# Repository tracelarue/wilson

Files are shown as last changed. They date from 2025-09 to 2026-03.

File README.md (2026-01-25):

# Wilson 🤖
A robot for autonomous beverage retrieval, powered by Gemini

Updated (9/30/25)

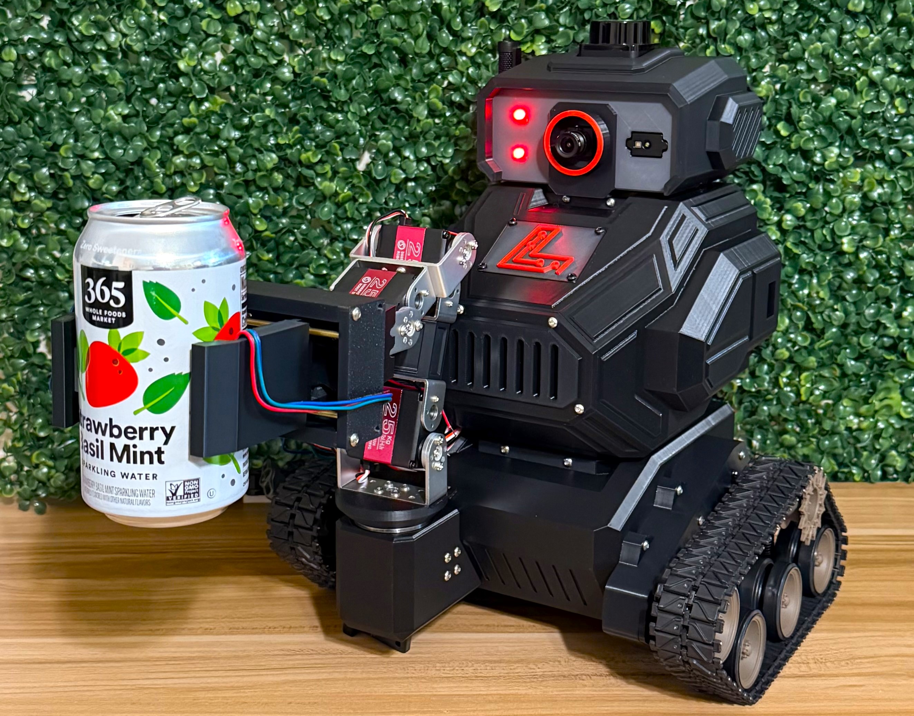
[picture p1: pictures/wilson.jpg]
Wilson Robot


## About Wilson

Wilson is an autonomous robot featuring a differential drive base and a 4-DOF manipulator arm, designed to be your personal beverage assistant! With Google's Gemini Live API, Wilson can conversationally interact with users and execute tasks based on natural language requests. His main directive? **Getting you a drink from the mini fridge!** *(in development)*

### Why I Built Wilson

I wanted to create a robot that could bridge the gap between advanced AI capabilities and real-world physical interaction. The goal was to build something impressive technically, build a robust set of robotics skills, and impress any guest who comes to my house - starting with the simple (but apparently not so simple), satisfying task of fetching drinks on command.

### How Wilson Works

Wilson operates on **ROS2 Humble** and combines a wide range of hardware and sensors:

**🧠 AI & Interaction:**
- Google Gemini Live API for natural conversation and task understanding
- Real-time audio/visual processing for environmental awareness
- Tool execution based on conversational commands

**🔧 Hardware:**
- **Computing**: Raspberry Pi 5 (8GB) as the main brain
- **Control**: 2 Arduino Nanos for drive and arm control
- **Sensors**: 
  - LD-19 LiDAR for navigation and mapping
  - AruCam ToF camera for depth perception  
  - USB camera for visual recognition
  - Microphone for listening to the user
  - Novel soft 3D force sensor in the gripper (developed by Dr. Jonathan Miller, et al. at the University of Kansas)
- **Motors**:
  - 2, GA37-520 DC motors with integrated encoders
  - 5, 20 kg digital servos
- **Power**:
  - 3S, 5200 mAh LiPo battery
- **Other**:
  - USB Speaker for responding to the user

## 🦾🔨 Design & Manufacturing

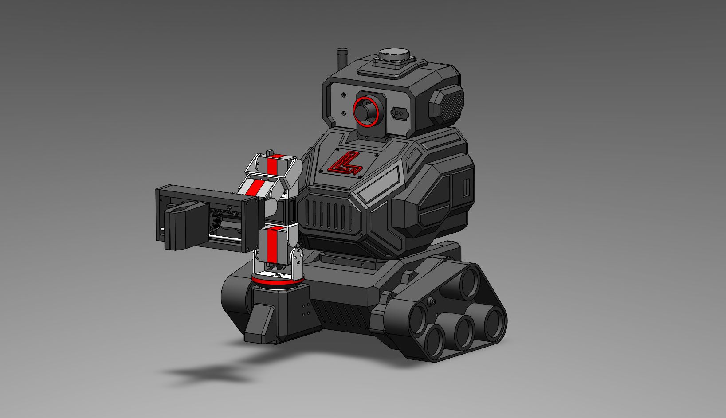
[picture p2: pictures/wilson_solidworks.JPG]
SolidWorks CAD Design

*SolidWorks CAD Design - The original 3D model*

I designed every component of Wilson (except the tracks/wheels) in SolidWorks and 3D printed the entire chassis and manipulator at home.

Wilson was designed with modularity and servicability in mind. The head, body, base, and track mounts are all seperate components to allow for easier fixes and design changes down the road. 

All of Wilson's electronic components are mounted internally on a modular rail system. This allows for easy removal of components for fixing or upgrading.

## Simulation & Testing 👨‍💻
Wilson's simulation leverages both **Gazebo** and **RViz** for an accelerated robotics development workflow:

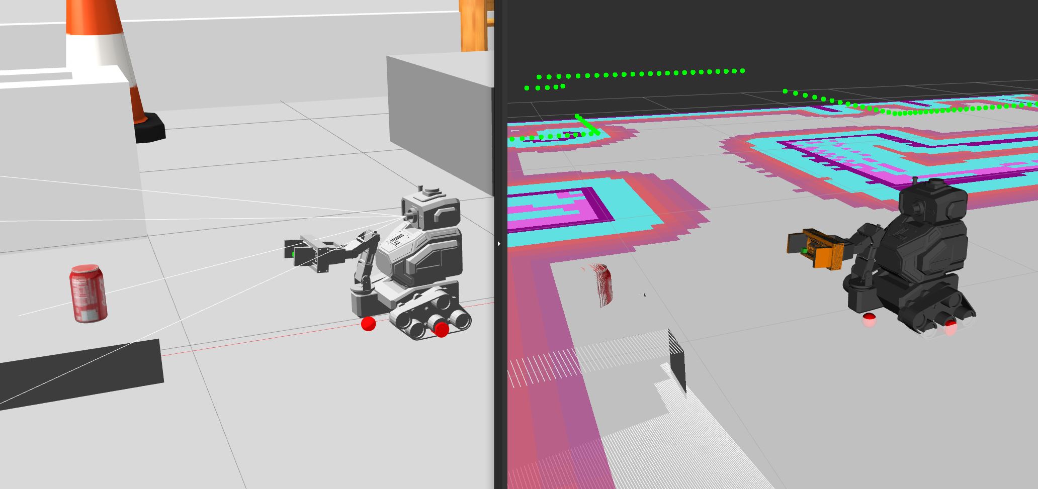
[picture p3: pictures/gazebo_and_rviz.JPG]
Gazebo wimulation with Rviz live data visualization


### Gazebo Simulation

Gazebo provides a realistic 3D environment where Wilson's physical model, sensors, and actuators are simulated. You can simulate Wilson navigating, manipulating objects, and interacting with its environment just like in the real world. The simulation includes:

- Physics-based movement and collisions
- Sensor emulation (LiDAR, cameras, force sensors)
- Interactive objects (Coke can)

### RViz Visualization

RViz is used for visualizing sensor data, robot state, and planning. In Wilson's simulation, RViz displays:

- The robot model
- Real-time LiDAR scans, depth camera point clouds, and images from a simulated camera
- Navigation maps and planned paths
- Manipulator arm trajectories
- AI-generated position markers for detected objects

You can use RViz panels to send navigation goals, control the arm, and monitor AI perception outputs. This combination of Gazebo and RViz enables rapid testing and debugging of Wilson's autonomous and conversational capabilities before deploying to hardware.

#### Navigation Demo
In this video, Wilson is asked to go to the living room. For the purpose of this demo, I have enabled text input and output, but when Wilson is aroudn the house, you would speak this command to him and he would respond accordingly.
AI controlled navigation demo

## Contact

Please feel free to submit issues or ideas for further improvement! 

Maintained by Trace LaRue:
traceglarue@gmail.com

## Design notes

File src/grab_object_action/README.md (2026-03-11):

# Grab Object Action Server

A ROS2 action server for grabbing drinks using MoveIt Task Constructor.

## Overview

This package provides an action server that accepts grab requests with drink coordinates in the `depth_camera_link_optical` frame and executes a grab sequence using MoveIt Task Constructor.

## Action Interface

### Action Name
`grab_object`

### Goal Message
```
float64 targetx                          # X-coordinate of drink (in depth_camera_link_optical frame)
float64 targety                          # Y-coordinate of drink (in depth_camera_link_optical frame)
float64 targetz                          # Z-coordinate of drink (in depth_camera_link_optical frame)
```

**Notes:**
- All coordinates are in the `depth_camera_link_optical` frame
- Drink dimensions are hardcoded (height: 0.122m, radius: 0.033m for standard can size)

### Feedback Message
```
string current_stage                     # Current execution stage
float32 progress_percentage              # Progress (0-100%)
```

### Result Message
```
bool success                             # Whether the grab succeeded
string message                           # Status/error message
geometry_msgs/Pose final_drink_pose      # Final drink pose in world frame
```

## Building

```bash
cd ~/wilson
colcon build --packages-select grab_object_action
source install/setup.bash
```

## Usage

### Launch the Action Server

```bash
ros2 launch grab_object_action grab_object_server.launch.py
```

### Send a Goal via Command Line

```bash
# Basic example - grab objectat x=0, y=0.1, z=0.65 in depth_camera_link_optical frame
ros2 action send_goal /grab_object grab_object_action/action/GrabObject "{
  targetx: 0.0,
  targety: 0.06,
  targetz: 0.375
}" --feedback
```

### Send a Goal from Python

```python
import rclpy
from rclpy.action import ActionClient
from rclpy.node import Node
from grab_object_action.action import GrabObject
from geometry_msgs.msg import Point

class GrabObjectClient(Node):
    def __init__(self):
        super().__init__('grab_object_client')
        self._action_client = ActionClient(self, GrabObject, 'grab_object')

    def send_goal(self, x, y, z):
        goal_msg = GrabObject.Goal()
        goal_msg.targetx = x
        goal_msg.targety = y
        goal_msg.targetz = z

        self._action_client.wait_for_server()

        send_goal_future = self._action_client.send_goal_async(
            goal_msg,
            feedback_callback=self.feedback_callback
        )
        send_goal_future.add_done_callback(self.goal_response_callback)

    def goal_response_callback(self, future):
        goal_handle = future.result()
        if not goal_handle.accepted:
            self.get_logger().info('Goal rejected')
            return

        self.get_logger().info('Goal accepted')
        result_future = goal_handle.get_result_async()
        result_future.add_done_callback(self.result_callback)

    def feedback_callback(self, feedback_msg):
        feedback = feedback_msg.feedback
        self.get_logger().info(f'Stage: {feedback.current_stage}, Progress: {feedback.progress_percentage}%')

    def result_callback(self, future):
        result = future.result().result
        if result.success:
            self.get_logger().info(f'Success! {result.message}')
        else:
            self.get_logger().error(f'Failed: {result.message}')

def main(args=None):
    rclpy.init(args=args)
    client = GrabObjectClient()

    # Example: grab object at position relative to depth camera
    client.send_goal(x=0.45, y=-0.07, z=0.1, frame='depth_camera_link_optical')

    rclpy.spin(client)

if __name__ == '__main__':
    main()
```

## Features

- **Dynamic Frame Transformation**: Automatically transforms target coordinates from the specified frame to the world frame
- **Standard Drink Dimensions**: Uses hardcoded dimensions optimized for standard can size (height: 0.122m, radius: 0.033m)
- **Progress Feedback**: Provides real-time feedback on execution progress
- **Dynamic Approach Vector**: Computes approach direction based on robot base position
- **Full Grab Sequence**: Executes complete grab sequence including:
  - Open gripper
  - Move to pre-grasp position
  - Approach drink
  - Generate grasp pose
  - Close gripper
  - Attach drink
  - Lift drink
  - Return home

## Configuration

The action server uses the following MoveIt group names (defined in the source code):
- **arm_group**: `"arm"`
- **hand_group**: `"gripper"`
- **hand_frame**: `"end_effector_frame"`

To change these, modify the constants in [src/grab_object_action_server.cpp](src/grab_object_action_server.cpp:334-336).

## Troubleshooting

### Action server not available
Make sure the action server is running and MoveIt is properly configured:
```bash
ros2 action list
# Should show: /grab_object
```

### Transform errors
Ensure all required TF frames are being published:
```bash
ros2 run tf2_ros tf2_echo base_link depth_camera_link_optical
```

### Planning failures
Check that:
1. The target position is reachable
2. MoveIt is properly configured for your robot
3. Collision checking is not too restrictive

## Dependencies

- `rclcpp`
- `rclcpp_action`
- `moveit_task_constructor_core`
- `tf2_ros`
- `geometry_msgs`
- `shape_msgs`

## License

TODO: Add license information

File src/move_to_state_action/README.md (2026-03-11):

# move_to_state_action

ROS2 Humble action server for moving robot groups to named states using MoveIt. This package provides a simple, reusable interface for commanding the robot to move to predefined poses defined in the SRDF.

## Overview

The `move_to_state_action` package provides an action server that:
1. Accepts a named state as input (e.g., "ready", "zero", "open")
2. Automatically detects which MoveIt planning group the state belongs to
3. Plans and executes motion to reach the target state
4. Provides real-time feedback during planning and execution

**Key Feature**: Field names have **no underscores** (`statename` instead of `state_name`) for full compatibility with MCP (Model Context Protocol) servers.

## Features

- **Auto-Detection**: Automatically determines which group (arm/gripper) a state belongs to by querying the SRDF
- **Simple Interface**: Single string input - just provide the state name
- **MCP Compatible**: Field names without underscores work seamlessly with MCP servers
- **Safe Execution**: Uses MoveIt's collision checking and motion planning
- **Real-time Feedback**: Progress updates during planning and execution
- **Error Handling**: Graceful handling of invalid states, planning failures, and execution errors

## Prerequisites

### System Requirements
- ROS2 Humble
- MoveIt 2
- Robot with SRDF containing named group states

### Available States (Wilson Robot)

Based on [wilson.srdf](../wilson_moveit_config/config/wilson.srdf):

**Arm States:**
- `ready` - Default ready position
- `idle` - Idle/rest position
- `zero` - All joints at zero
- `ready_to_grab` - Pre-grasp position
- `ground_grab` - Low grabbing position
- `air_grab` - Mid-air grabbing position

**Gripper States:**
- `open` - Gripper fully open
- `close` - Gripper fully closed
- `can` - Gripper sized for a can

## Installation

1. Package is located in your ROS2 workspace:
   ```bash
   cd ~/wilson/src/move_to_state_action
   ```

2. Build the package:
   ```bash
   cd ~/wilson
   colcon build --packages-select move_to_state_action --symlink-install
   source install/setup.bash
   ```

## Usage

### Launch the Action Server

```bash
# Source your workspace
source ~/wilson/install/setup.bash

# Launch the action server
ros2 launch move_to_state_action move_to_state_server.launch.py

# For simulation (with sim time)
ros2 launch move_to_state_action move_to_state_server.launch.py use_sim_time:=true
```

### Send Action Goals

**Command Line:**
```bash
# Move arm to ready position
ros2 action send_goal /move_to_state move_to_state_action/action/MoveToState \
  "{statename: 'idle'}" --feedback

# Move arm to zero position
ros2 action send_goal /move_to_state move_to_state_action/action/MoveToState \
  "{statename: 'zero'}" --feedback

# Open gripper
ros2 action send_goal /move_to_state move_to_state_action/action/MoveToState \
  "{statename: 'open'}" --feedback

# Close gripper to can size
ros2 action send_goal /move_to_state move_to_state_action/action/MoveToState \
  "{statename: 'can'}" --feedback
```

**Python Client:**
```python
import rclpy
from rclpy.action import ActionClient
from rclpy.node import Node
from move_to_state_action.action import MoveToState

class MoveToStateClient(Node):
    def __init__(self):
        super().__init__('move_to_state_client')
        self._action_client = ActionClient(self, MoveToState, 'move_to_state')

    def send_goal(self, state_name):
        goal_msg = MoveToState.Goal()
        goal_msg.statename = state_name  # Note: no underscore (MCP compatible!)

        self._action_client.wait_for_server()
        self._send_goal_future = self._action_client.send_goal_async(
            goal_msg, feedback_callback=self.feedback_callback)
        self._send_goal_future.add_done_callback(self.goal_response_callback)

    def feedback_callback(self, feedback_msg):
        feedback = feedback_msg.feedback
        self.get_logger().info(
            f'{feedback.currentstatus} ({feedback.progresspercentage:.1f}%)')

    def goal_response_callback(self, future):
        goal_handle = future.result()
        if not goal_handle.accepted:
            self.get_logger().info('Goal rejected')
            return

        self.get_logger().info('Goal accepted')
        self._get_result_future = goal_handle.get_result_async()
        self._get_result_future.add_done_callback(self.get_result_callback)

    def get_result_callback(self, future):
        result = future.result().result
        if result.success:
            self.get_logger().info(f'Success! {result.message}')
        else:
            self.get_logger().error(f'Failed: {result.message}')

def main(args=None):
    rclpy.init(args=args)
    client = MoveToStateClient()
    client.send_goal('ready')
    rclpy.spin(client)
    rclpy.shutdown()

if __name__ == '__main__':
    main()
```

**C++ Client:**
```cpp
#include <rclcpp/rclcpp.hpp>
#include <rclcpp_action/rclcpp_action.hpp>
#include "move_to_state_action/action/move_to_state.hpp"

using MoveToState = move_to_state_action::action::MoveToState;
using GoalHandleMoveToState = rclcpp_action::ClientGoalHandle<MoveToState>;

class MoveToStateClient : public rclcpp::Node {
public:
    MoveToStateClient() : Node("move_to_state_client") {
        client_ = rclcpp_action::create_client<MoveToState>(this, "move_to_state");
    }

    void send_goal(const std::string& state_name) {
        if (!client_->wait_for_action_server(std::chrono::seconds(10))) {
            RCLCPP_ERROR(this->get_logger(), "Action server not available");
            return;
        }

        auto goal_msg = MoveToState::Goal();
        goal_msg.statename = state_name;  // Note: no underscore (MCP compatible!)

        auto send_goal_options = rclcpp_action::Client<MoveToState>::SendGoalOptions();
        send_goal_options.feedback_callback =
            [this](auto, const auto feedback) {
                RCLCPP_INFO(this->get_logger(), "%s (%.1f%%)",
                    feedback->currentstatus.c_str(),
                    feedback->progresspercentage);
            };

        client_->async_send_goal(goal_msg, send_goal_options);
    }

private:
    rclcpp_action::Client<MoveToState>::SharedPtr client_;
};
```

## Action Interface

### Goal
```
string statename    # Name of the state (e.g., "ready", "zero", "open")
```

### Result
```
bool success        # True if motion completed successfully
string message      # Status message (success or error description)
```

### Feedback
```
string currentstatus         # Current operation status
float32 progresspercentage   # Progress from 0.0 to 100.0
```

## MCP Server Compatibility

This action is designed for full compatibility with MCP (Model Context Protocol) servers, which have issues with underscores in field names.

**Field Names (No Underscores):**
- ✅ `statename` (not `state_name`)
- ✅ `currentstatus` (not `current_status`)
- ✅ `progresspercentage` (not `progress_percentage`)

This allows seamless integration with Gemini AI tools and other MCP-based systems.

## Topics and Services

### Action Servers
- `/move_to_state` (move_to_state_action/action/MoveToState): Main action interface

## Architecture

### State Detection Flow
1. **Load Robot Model**: Query robot_description to access SRDF
2. **Scan Groups**: Check each MoveIt planning group (arm, gripper, arm_gripper)
3. **Find State**: Search for the requested state name in group's default states
4. **Return Group**: Return the first group containing the state

### Execution Flow
1. **Detect Group**: Automatically determine which group the state belongs to
2. **Initialize MoveGroup**: Create MoveGroupInterface for the detected group
3. **Set Target**: Use `setNamedTarget(statename)`
4. **Plan**: Generate collision-free trajectory
5. **Execute**: Execute the planned trajectory
6. **Verify**: Return success/failure result

## Error Handling

The action server handles various failure scenarios:

- **State Not Found**: Returns error if state doesn't exist in any group
- **Planning Failure**: Returns error if no valid path can be found
- **Execution Failure**: Returns error if trajectory execution fails
- **Cancellation**: Supports goal cancellation before and during execution

## Common Issues and Solutions

### "State 'xyz' not found in SRDF"
- Check that the state is defined in your SRDF file
- Verify state name spelling matches exactly (case-sensitive)
- Ensure SRDF is loaded correctly in robot_description

### "Motion planning failed"
- Check if target state is kinematically reachable
- Verify joint limits in MoveIt configuration
- Increase planning time if needed
- Check for collision constraints

### "Action server not available"
- Ensure action server is launched: `ros2 node list | grep move_to_state`
- Check MoveIt move_group is running
- Verify robot_description is published

## Integration with Wilson

This package integrates with the Wilson robot system:

1. **Add to Main Launch** (optional - can be launched separately):
   ```python
   from launch.actions import IncludeLaunchDescription
   from launch.launch_description_sources import PythonLaunchDescriptionSource

   move_to_state_server = IncludeLaunchDescription(
       PythonLaunchDescriptionSource([
           os.path.join(get_package_share_directory('move_to_state_action'),
                       'launch', 'move_to_state_server.launch.py')
       ]),
       launch_arguments={'use_sim_time': use_sim_time}.items()
   )
   ```

2. **Call from Gemini AI** (MCP compatible):
   ```python
   def move_to_state_tool(self, statename: str):
       """Tool for Gemini to move robot to named states."""
       goal = MoveToState.Goal()
       goal.statename = statename  # MCP-compatible field name!

       future = self.move_to_state_client.send_goal_async(goal)
       # Handle result...
   ```

## Development

### Adding New States

1. Edit your SRDF file:
   ```xml
   <group_state name="my_new_state" group="arm">
       <joint name="joint_1" value="0.5"/>
       <joint name="joint_2" value="1.0"/>
       <!-- ... -->
   </group_state>
   ```

2. Reload robot description (restart MoveIt)

3. Test the new state:
   ```bash
   ros2 action send_goal /move_to_state move_to_state_action/action/MoveToState \
     "{statename: 'my_new_state'}" --feedback
   ```

### Debugging

Enable detailed logging:
```bash
ros2 run move_to_state_action move_to_state_action_server --ros-args \
  --log-level move_to_state_action_server:=debug
```

Monitor action feedback:
```bash
ros2 action send_goal /move_to_state move_to_state_action/action/MoveToState \
  "{statename: 'ready'}" --feedback
```

## Comparison with Alternatives

### vs Direct MoveGroupInterface
- ✅ **move_to_state_action**: Provides action interface with feedback, cancellation, async execution
- ❌ **Direct MoveGroup**: Requires manual node creation, no standardized interface

### vs MoveIt Task Constructor
- ✅ **move_to_state_action**: Simple, fast for basic moves to named states
- ❌ **MTC**: Overkill for simple named state moves, but better for complex multi-stage tasks

### vs Service Interface
- ✅ **move_to_state_action**: Supports feedback, cancellation, progress updates
- ❌ **Service**: No feedback during execution, no cancellation support

## License

MIT License

## Author

Created for the Wilson autonomous robot project.

## References

- [ROS2 Actions Documentation](https://docs.ros.org/en/humble/Tutorials/Intermediate/Writing-an-Action-Server-Client/Cpp.html)
- [MoveIt 2 Documentation](https://moveit.picknik.ai/main/index.html)
- [Wilson Robot Documentation](../README.md)
- [MCP Protocol](https://modelcontextprotocol.io/)

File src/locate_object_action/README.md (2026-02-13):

# locate_object_action

ROS2 Humble action server package for robotic drink localization using Gemini AI computer vision. This package enables a differential-drive robot to detect a specified drink using camera input and position itself optimally relative to the drink.

## Overview

The `locate_object_action` package provides an action server that:
1. Uses Gemini AI to detect and localize a drink by name in camera images
2. Calculates the 3D position of the drink relative to the camera frame
3. Controls the robot's differential drive base to achieve optimal positioning
4. Provides real-time feedback on detection status and positioning errors

## Features

- **AI-Powered Detection**: Uses Google's Gemini 2.0 Flash model for robust drink detection
- **3D Localization**: Combines RGB and depth camera data for accurate positioning
- **Adaptive Control**: Proportional controller for smooth robot movement
- **Configurable Parameters**: All control gains, tolerances, and timeouts adjustable via YAML
- **Visual Debug Frames**: Optional annotated RGB/depth topics to inspect bbox and depth sampling
- **Comprehensive Feedback**: Real-time status updates during positioning
- **Error Handling**: Robust error handling for API failures, timeouts, and detection failures

## Prerequisites

### System Requirements
- ROS2 Humble
- Python 3.10+
- RGB and Depth camera (e.g., Intel RealSense, Arducam ToF)
- Differential drive robot base

### Python Dependencies
Install the required Python packages:
```bash
pip3 install google-genai opencv-python pillow python-dotenv numpy
```

### API Key
You need a Google API key for Gemini AI. Create a `.env` file in your workspace root:
```bash
# /home/trace/wilson/.env
GOOGLE_API_KEY="your_api_key_here"
```

Get your API key from: https://aistudio.google.com/apikey

## Installation

1. Clone or copy this package to your ROS2 workspace:
   ```bash
   cd ~/wilson/src
   # Package should be in: src/locate_object_action/
   ```

2. Build the package:
   ```bash
   cd ~/wilson
   colcon build --packages-select locate_object_action --symlink-install
   source install/setup.bash
   ```

## Usage

### Launch the Action Server

```bash
# Source your workspace
source ~/wilson/install/setup.bash

# Launch the action server
ros2 launch locate_object_action locate_object_server.launch.py
```

### Send an Action Goal

Using the command line:
```bash
ros2 action send_goal /locate_object locate_object_action/action/LocateObject \
  "{objectname: 'soda'}" --feedback
```

Using Python:
```python
import rclpy
from rclpy.action import ActionClient
from rclpy.node import Node
from locate_object_action.action import LocateObject

class LocateObjectClient(Node):
    def __init__(self):
        super().__init__('locate_object_client')
        self._action_client = ActionClient(self, LocateObject, 'locate_object')

    def send_goal(self, drink_name):
        goal_msg = LocateObject.Goal()
        goal_msg.objectname = drink_name

        self._action_client.wait_for_server()
        self._send_goal_future = self._action_client.send_goal_async(
            goal_msg, feedback_callback=self.feedback_callback)
        self._send_goal_future.add_done_callback(self.goal_response_callback)

    def feedback_callback(self, feedback_msg):
        feedback = feedback_msg.feedback
        self.get_logger().info(f'Status: {feedback.current_status}')
        self.get_logger().info(f'Position: x={feedback.current_position.x:.3f}, z={feedback.current_position.z:.3f}')
        self.get_logger().info(f'Errors: x={feedback.error_x:.3f}, z={feedback.error_z:.3f}')

    def goal_response_callback(self, future):
        goal_handle = future.result()
        if not goal_handle.accepted:
            self.get_logger().info('Goal rejected')
            return

        self.get_logger().info('Goal accepted')
        self._get_result_future = goal_handle.get_result_async()
        self._get_result_future.add_done_callback(self.get_result_callback)

    def get_result_callback(self, future):
        result = future.result().result
        if result.success:
            self.get_logger().info(f'Success! {result.message}')
            self.get_logger().info(f'Final position: x={result.final_position.x:.3f}, z={result.final_position.z:.3f}')
        else:
            self.get_logger().error(f'Failed: {result.message}')

def main(args=None):
    rclpy.init(args=args)
    client = LocateObjectClient()
    client.send_goal('Sprite')
    rclpy.spin(client)
    rclpy.shutdown()

if __name__ == '__main__':
    main()
```

## Configuration

All parameters are configurable via [config/locate_object_params.yaml](config/locate_object_params.yaml):

### Target Position Parameters
- `target_x` (default: 0.0): Target horizontal position in meters (centered in camera view)
- `target_z` (default: 0.4): Target distance from camera in meters
- `x_tolerance` (default: 0.05): Horizontal tolerance in meters for successful positioning
- `z_tolerance` (default: 0.05): Distance tolerance in meters for successful positioning

### Control Parameters
- `k_linear` (default: 0.5): Linear velocity proportional gain
- `k_linear_i` (default: 0.0): Linear velocity integral gain
- `k_angular` (default: 1.0): Angular velocity proportional gain
- `k_angular_i` (default: 0.0): Angular velocity integral gain
- `linear_integral_limit` (default: 0.2): Anti-windup clamp for linear integral state
- `angular_integral_limit` (default: 0.2): Anti-windup clamp for angular integral state
- `max_linear_vel` (default: 0.3): Maximum linear velocity in m/s
- `max_angular_vel` (default: 0.5): Maximum angular velocity in rad/s
- `min_movement_threshold` (default: 0.005): Minimum velocity to prevent oscillations
- `z_offset_correction` (default: 0.033): Distance correction added to raw detected z before control

### Camera Parameters
- `h_fov` (default: 1.089): Horizontal field of view in radians
- `aspect_ratio` (default: 1.333): Image aspect ratio (width/height)
- `camera_frame` (default: 'depth_camera_link_optical'): TF frame for camera
- `image_width` (default: 640): Image width in pixels
- `image_height` (default: 480): Image height in pixels
- `depth_sample_size` (default: 5): NxN window size for depth averaging
- `bbox_shift_ratio` (default: 0.0): Horizontal shift ratio for depth sampling (compensates for RGB/depth camera offset)

### Y-Value Override Parameters (Debugging/Calibration)
- `override_y_value` (default: false): Enable to force Y-coordinate to a fixed value instead of using calculated value from depth camera
- `fixed_y_value` (default: 0.1): Fixed Y value in meters when `override_y_value` is enabled

**Note:** The Y-value override is useful for debugging vertical positioning issues or when the depth camera's vertical calibration is inaccurate. When enabled, the returned Y-coordinate will always be the `fixed_y_value` regardless of the detected drink's actual vertical position. This is applied at the last moment before returning the 3D position. Set `override_y_value: false` to disable and use the calculated Y-coordinate.

### Operation Parameters
- `max_detection_attempts` (default: 5): Maximum detection retries before failure
- `control_loop_rate` (default: 2.0): Control loop frequency in Hz
- `overall_timeout` (default: 60.0): Overall operation timeout in seconds
- `api_timeout` (default: 10.0): Gemini API timeout in seconds
- `movement_settle_time` (default: 0.5): Wait time after velocity commands in seconds

## Action Interface

### Goal
```
string objectname  # Name of the drink to locate (e.g., "Coca Cola", "Sprite", "Water bottle")
```

### Result
```
bool success                      # True if positioning successful
string message                    # Status message
geometry_msgs/Point final_position  # Final 3D position (x, y, z) in meters
```

### Feedback
```
string current_status              # Current operation status
geometry_msgs/Point current_position  # Current drink position (x, y, z) in meters
float32 error_x                    # Horizontal error from target in meters
float32 error_z                    # Distance error from target in meters
uint8 detection_attempts           # Number of detection attempts made
```

## Coordinate System

The action server operates in the `depth_camera_link_optical` frame:
- **X-axis**: Horizontal (positive = right from camera's view)
- **Y-axis**: Vertical (positive = down from camera's view) - *not controlled by robot movement*
- **Z-axis**: Depth/distance from camera (positive = forward)

**Target Position** (configurable):
- `x = 0.0`: Drink centered horizontally in camera view
- `z = 0.4`: Drink is 0.4 meters from the camera

The robot moves via differential drive (`/cmd_vel`) to minimize the error between the current and target positions.

**Y-Value Override:**
The Y-coordinate can be manually overridden for debugging/calibration purposes. When `override_y_value: true` in the config, the returned Y-coordinate will always be `fixed_y_value` instead of the calculated value. This is useful when:
- Testing vertical positioning without a properly calibrated depth camera
- Debugging issues with vertical coordinate calculations
- The depth camera's vertical FOV or alignment is inaccurate

To disable the override and use the actual calculated Y-coordinate, set `override_y_value: false` in your config file.

### Visual Debug Parameters
- `enable_debug_frames` (default: false): Publish annotated debug images for detection and depth sampling
- `debug_rgb_topic` (default: `/locate_object/debug/rgb`): RGB frame with detected bbox and center
- `debug_depth_topic` (default: `/locate_object/debug/depth`): Colorized depth frame with shifted depth sample window

## Topics

### Subscribed Topics
- `/rgb_camera/image_raw` (sensor_msgs/Image): RGB camera feed
- `/depth_camera/depth/image_raw` (sensor_msgs/Image): Depth camera feed

### Published Topics
- `/cmd_vel` (geometry_msgs/Twist): Velocity commands for differential drive base
- `/locate_object/debug/rgb` (sensor_msgs/Image): Annotated RGB detection frame (when `enable_debug_frames=true`)
- `/locate_object/debug/depth` (sensor_msgs/Image): Annotated depth sampling frame (when `enable_debug_frames=true`)

### Action Servers
- `/locate_object` (locate_object_action/action/LocateObject): Main action interface

## Architecture

### Detection Pipeline
1. **Image Acquisition**: Capture synchronized RGB and depth images
2. **AI Detection**: Send RGB image to Gemini AI with object name
3. **Bounding Box Extraction**: Parse JSON response for drink location
4. **Depth Lookup**: Extract depth value at bounding box center
5. **3D Calculation**: Project pixel coordinates to 3D using camera FOV and depth

### Control Loop
1. **Detect & Localize**: Get current drink position (x, z)
2. **Calculate Error**: `error_x = current_x - target_x`, `error_z = current_z - target_z`
3. **Proportional Control**:
   - Linear velocity: `v = k_linear * error_z` (move forward/back)
   - Angular velocity: `ω = -k_angular * error_x` (rotate left/right)
4. **Send Commands**: Publish to `/cmd_vel` with velocity limits
5. **Check Convergence**: Success if `|error_x| < x_tolerance` AND `|error_z| < z_tolerance`
6. **Repeat**: Continue until converged or timeout

## Error Handling

The action server handles various failure scenarios:

- **Drink Not Detected**: Retries up to `max_detection_attempts` times
- **API Timeout**: Returns failure with clear error message
- **Camera Unavailable**: Waits briefly for camera data, fails if unavailable
- **Overall Timeout**: Aborts operation after `overall_timeout` seconds
- **Goal Cancellation**: Stops robot and returns cancelled status

## Tuning Guide

### Improving Detection Accuracy
1. Ensure good lighting conditions
2. Use specific object names (e.g., "red Coca Cola can" vs "drink")
3. Adjust camera position for clear view
4. Increase `max_detection_attempts` if environment is cluttered

### Improving Positioning Performance
1. **Faster Convergence**: Increase `k_linear` and `k_angular` gains
2. **Smoother Motion**: Decrease gains, reduce `max_linear_vel` and `max_angular_vel`
3. **Reduce Oscillations**: Increase `min_movement_threshold`
4. **Tighter Tolerance**: Decrease `x_tolerance` and/or `z_tolerance` (requires more precise control)
5. **Independent Tuning**: Adjust `x_tolerance` and `z_tolerance` separately to optimize horizontal vs distance positioning

### Reducing API Costs
1. Decrease `control_loop_rate` (fewer API calls per second)
2. Increase `movement_settle_time` (allow more time between detections)
3. Implement caching or tracking (future enhancement)

## Troubleshooting

### "Camera data not available"
- Check camera is publishing: `ros2 topic list | grep camera`
- Verify topic names match parameters
- Check camera node is running

### "Failed to detect drink"
- Ensure drink is visible in camera view
- Try more specific drink descriptions
- Check lighting conditions
- Verify GOOGLE_API_KEY is set correctly

### Robot moves erratically
- Reduce control gains (`k_linear`, `k_angular`)
- Decrease velocity limits
- Increase `movement_settle_time`
- Check for controller conflicts (other nodes publishing to `/cmd_vel`)

### "Timeout after X seconds"
- Increase `overall_timeout`
- Increase `control_loop_rate` for faster convergence
- Check if robot is physically able to reach target position

## Integration with Wilson

This package is designed to work with the Wilson robot system. To integrate:

1. Add to Wilson's main launch file:
   ```python
   locate_object_server = IncludeLaunchDescription(
       PythonLaunchDescriptionSource([
           os.path.join(get_package_share_directory('locate_object_action'), 'launch', 'locate_object_server.launch.py')
       ]),
       launch_arguments={'use_sim_time': use_sim_time}.items()
   )
   ```

2. Call from Gemini AI tools:
   ```python
   def locate_object_tool(self, drink_name):
       """Tool for Gemini to locate objects."""
       goal = LocateObject.Goal()
       goal.objectname = drink_name

       future = self.locate_object_client.send_goal_async(goal)
       # Handle result...
   ```

## Future Enhancements

Potential improvements:
- [ ] Object tracking to reduce API calls
- [ ] Multiple drink detection and selection
- [ ] Integration with MoveIt for arm reaching
- [ ] Visual servoing for finer positioning
- [ ] Obstacle avoidance during positioning
- [ ] Dynamic reconfiguration of parameters
- [ ] Support for different camera types/calibrations

## License

MIT License

## Author

Created for the Wilson autonomous robot project.

## References

- [ROS2 Actions Documentation](https://docs.ros.org/en/humble/Tutorials/Intermediate/Writing-an-Action-Server-Client/Py.html)
- [Google Gemini API](https://ai.google.dev/docs)
- [Wilson Robot Documentation](../README.md)

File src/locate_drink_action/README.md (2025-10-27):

# locate_drink_action

ROS2 Humble action server package for robotic drink localization using Gemini AI computer vision. This package enables a differential-drive robot to detect a specified drink using camera input and position itself optimally relative to the drink.

## Overview

The `locate_drink_action` package provides an action server that:
1. Uses Gemini AI to detect and localize a drink by name in camera images
2. Calculates the 3D position of the drink relative to the camera frame
3. Controls the robot's differential drive base to achieve optimal positioning
4. Provides real-time feedback on detection status and positioning errors

## Features

- **AI-Powered Detection**: Uses Google's Gemini 2.0 Flash model for robust drink detection
- **3D Localization**: Combines RGB and depth camera data for accurate positioning
- **Adaptive Control**: Proportional controller for smooth robot movement
- **Configurable Parameters**: All control gains, tolerances, and timeouts adjustable via YAML
- **Comprehensive Feedback**: Real-time status updates during positioning
- **Error Handling**: Robust error handling for API failures, timeouts, and detection failures

## Prerequisites

### System Requirements
- ROS2 Humble
- Python 3.10+
- RGB and Depth camera (e.g., Intel RealSense, Arducam ToF)
- Differential drive robot base

### Python Dependencies
Install the required Python packages:
```bash
pip3 install google-genai opencv-python pillow python-dotenv numpy
```

### API Key
You need a Google API key for Gemini AI. Create a `.env` file in your workspace root:
```bash
# /home/trace/wilson/.env
GOOGLE_API_KEY="your_api_key_here"
```

Get your API key from: https://aistudio.google.com/apikey

## Installation

1. Clone or copy this package to your ROS2 workspace:
   ```bash
   cd ~/wilson/src
   # Package should be in: src/locate_drink_action/
   ```

2. Build the package:
   ```bash
   cd ~/wilson
   colcon build --packages-select locate_drink_action --symlink-install
   source install/setup.bash
   ```

## Usage

### Launch the Action Server

```bash
# Source your workspace
source ~/wilson/install/setup.bash

# Launch the action server
ros2 launch locate_drink_action locate_drink_server.launch.py
```

### Send an Action Goal

Using the command line:
```bash
ros2 action send_goal /locate_drink locate_drink_action/action/LocateDrink \
  "{drinkname: 'soda'}" --feedback
```

Using Python:
```python
import rclpy
from rclpy.action import ActionClient
from rclpy.node import Node
from locate_drink_action.action import LocateDrink

class LocateDrinkClient(Node):
    def __init__(self):
        super().__init__('locate_drink_client')
        self._action_client = ActionClient(self, LocateDrink, 'locate_drink')

    def send_goal(self, drink_name):
        goal_msg = LocateDrink.Goal()
        goal_msg.drinkname = drink_name

        self._action_client.wait_for_server()
        self._send_goal_future = self._action_client.send_goal_async(
            goal_msg, feedback_callback=self.feedback_callback)
        self._send_goal_future.add_done_callback(self.goal_response_callback)

    def feedback_callback(self, feedback_msg):
        feedback = feedback_msg.feedback
        self.get_logger().info(f'Status: {feedback.current_status}')
        self.get_logger().info(f'Position: x={feedback.current_position.x:.3f}, z={feedback.current_position.z:.3f}')
        self.get_logger().info(f'Errors: x={feedback.error_x:.3f}, z={feedback.error_z:.3f}')

    def goal_response_callback(self, future):
        goal_handle = future.result()
        if not goal_handle.accepted:
            self.get_logger().info('Goal rejected')
            return

        self.get_logger().info('Goal accepted')
        self._get_result_future = goal_handle.get_result_async()
        self._get_result_future.add_done_callback(self.get_result_callback)

    def get_result_callback(self, future):
        result = future.result().result
        if result.success:
            self.get_logger().info(f'Success! {result.message}')
            self.get_logger().info(f'Final position: x={result.final_position.x:.3f}, z={result.final_position.z:.3f}')
        else:
            self.get_logger().error(f'Failed: {result.message}')

def main(args=None):
    rclpy.init(args=args)
    client = LocateDrinkClient()
    client.send_goal('Sprite')
    rclpy.spin(client)
    rclpy.shutdown()

if __name__ == '__main__':
    main()
```

## Configuration

All parameters are configurable via [config/locate_drink_params.yaml](config/locate_drink_params.yaml):

### Target Position Parameters
- `target_x` (default: 0.0): Target horizontal position in meters (centered in camera view)
- `target_z` (default: 0.4): Target distance from camera in meters
- `x_tolerance` (default: 0.05): Horizontal tolerance in meters for successful positioning
- `z_tolerance` (default: 0.05): Distance tolerance in meters for successful positioning

### Control Parameters
- `k_linear` (default: 0.5): Linear velocity proportional gain
- `k_angular` (default: 1.0): Angular velocity proportional gain
- `max_linear_vel` (default: 0.3): Maximum linear velocity in m/s
- `max_angular_vel` (default: 0.5): Maximum angular velocity in rad/s
- `min_movement_threshold` (default: 0.005): Minimum velocity to prevent oscillations

### Camera Parameters
- `h_fov` (default: 1.089): Horizontal field of view in radians
- `aspect_ratio` (default: 1.333): Image aspect ratio (width/height)
- `camera_frame` (default: 'depth_camera_link_optical'): TF frame for camera
- `image_width` (default: 640): Image width in pixels
- `image_height` (default: 480): Image height in pixels
- `depth_sample_size` (default: 5): NxN window size for depth averaging
- `bbox_shift_ratio` (default: 0.0): Horizontal shift ratio for depth sampling (compensates for RGB/depth camera offset)

### Y-Value Override Parameters (Debugging/Calibration)
- `override_y_value` (default: false): Enable to force Y-coordinate to a fixed value instead of using calculated value from depth camera
- `fixed_y_value` (default: 0.1): Fixed Y value in meters when `override_y_value` is enabled

**Note:** The Y-value override is useful for debugging vertical positioning issues or when the depth camera's vertical calibration is inaccurate. When enabled, the returned Y-coordinate will always be the `fixed_y_value` regardless of the detected drink's actual vertical position. This is applied at the last moment before returning the 3D position. Set `override_y_value: false` to disable and use the calculated Y-coordinate.

### Operation Parameters
- `max_detection_attempts` (default: 5): Maximum detection retries before failure
- `control_loop_rate` (default: 2.0): Control loop frequency in Hz
- `overall_timeout` (default: 60.0): Overall operation timeout in seconds
- `api_timeout` (default: 10.0): Gemini API timeout in seconds
- `movement_settle_time` (default: 0.5): Wait time after velocity commands in seconds

## Action Interface

### Goal
```
string drinkname  # Name of the drink to locate (e.g., "Coca Cola", "Sprite", "Water bottle")
```

### Result
```
bool success                      # True if positioning successful
string message                    # Status message
geometry_msgs/Point final_position  # Final 3D position (x, y, z) in meters
```

### Feedback
```
string current_status              # Current operation status
geometry_msgs/Point current_position  # Current drink position (x, y, z) in meters
float32 error_x                    # Horizontal error from target in meters
float32 error_z                    # Distance error from target in meters
uint8 detection_attempts           # Number of detection attempts made
```

## Coordinate System

The action server operates in the `depth_camera_link_optical` frame:
- **X-axis**: Horizontal (positive = right from camera's view)
- **Y-axis**: Vertical (positive = down from camera's view) - *not controlled by robot movement*
- **Z-axis**: Depth/distance from camera (positive = forward)

**Target Position** (configurable):
- `x = 0.0`: Drink centered horizontally in camera view
- `z = 0.4`: Drink is 0.4 meters from the camera

The robot moves via differential drive (`/cmd_vel`) to minimize the error between the current and target positions.

**Y-Value Override:**
The Y-coordinate can be manually overridden for debugging/calibration purposes. When `override_y_value: true` in the config, the returned Y-coordinate will always be `fixed_y_value` instead of the calculated value. This is useful when:
- Testing vertical positioning without a properly calibrated depth camera
- Debugging issues with vertical coordinate calculations
- The depth camera's vertical FOV or alignment is inaccurate

To disable the override and use the actual calculated Y-coordinate, set `override_y_value: false` in your config file.

## Topics

### Subscribed Topics
- `/rgb_camera/image_raw` (sensor_msgs/Image): RGB camera feed
- `/depth_camera/depth/image_raw` (sensor_msgs/Image): Depth camera feed

### Published Topics
- `/cmd_vel` (geometry_msgs/Twist): Velocity commands for differential drive base

### Action Servers
- `/locate_drink` (locate_drink_action/action/LocateDrink): Main action interface

## Architecture

### Detection Pipeline
1. **Image Acquisition**: Capture synchronized RGB and depth images
2. **AI Detection**: Send RGB image to Gemini AI with drink name
3. **Bounding Box Extraction**: Parse JSON response for drink location
4. **Depth Lookup**: Extract depth value at bounding box center
5. **3D Calculation**: Project pixel coordinates to 3D using camera FOV and depth

### Control Loop
1. **Detect & Localize**: Get current drink position (x, z)
2. **Calculate Error**: `error_x = current_x - target_x`, `error_z = current_z - target_z`
3. **Proportional Control**:
   - Linear velocity: `v = k_linear * error_z` (move forward/back)
   - Angular velocity: `ω = -k_angular * error_x` (rotate left/right)
4. **Send Commands**: Publish to `/cmd_vel` with velocity limits
5. **Check Convergence**: Success if `|error_x| < x_tolerance` AND `|error_z| < z_tolerance`
6. **Repeat**: Continue until converged or timeout

## Error Handling

The action server handles various failure scenarios:

- **Drink Not Detected**: Retries up to `max_detection_attempts` times
- **API Timeout**: Returns failure with clear error message
- **Camera Unavailable**: Waits briefly for camera data, fails if unavailable
- **Overall Timeout**: Aborts operation after `overall_timeout` seconds
- **Goal Cancellation**: Stops robot and returns cancelled status

## Tuning Guide

### Improving Detection Accuracy
1. Ensure good lighting conditions
2. Use specific drink names (e.g., "red Coca Cola can" vs "drink")
3. Adjust camera position for clear view
4. Increase `max_detection_attempts` if environment is cluttered

### Improving Positioning Performance
1. **Faster Convergence**: Increase `k_linear` and `k_angular` gains
2. **Smoother Motion**: Decrease gains, reduce `max_linear_vel` and `max_angular_vel`
3. **Reduce Oscillations**: Increase `min_movement_threshold`
4. **Tighter Tolerance**: Decrease `x_tolerance` and/or `z_tolerance` (requires more precise control)
5. **Independent Tuning**: Adjust `x_tolerance` and `z_tolerance` separately to optimize horizontal vs distance positioning

### Reducing API Costs
1. Decrease `control_loop_rate` (fewer API calls per second)
2. Increase `movement_settle_time` (allow more time between detections)
3. Implement caching or tracking (future enhancement)

## Troubleshooting

### "Camera data not available"
- Check camera is publishing: `ros2 topic list | grep camera`
- Verify topic names match parameters
- Check camera node is running

### "Failed to detect drink"
- Ensure drink is visible in camera view
- Try more specific drink descriptions
- Check lighting conditions
- Verify GOOGLE_API_KEY is set correctly

### Robot moves erratically
- Reduce control gains (`k_linear`, `k_angular`)
- Decrease velocity limits
- Increase `movement_settle_time`
- Check for controller conflicts (other nodes publishing to `/cmd_vel`)

### "Timeout after X seconds"
- Increase `overall_timeout`
- Increase `control_loop_rate` for faster convergence
- Check if robot is physically able to reach target position

## Integration with Wilson

This package is designed to work with the Wilson robot system. To integrate:

1. Add to Wilson's main launch file:
   ```python
   locate_drink_server = IncludeLaunchDescription(
       PythonLaunchDescriptionSource([
           os.path.join(get_package_share_directory('locate_drink_action'), 'launch', 'locate_drink_server.launch.py')
       ]),
       launch_arguments={'use_sim_time': use_sim_time}.items()
   )
   ```

2. Call from Gemini AI tools:
   ```python
   def locate_drink_tool(self, drink_name):
       """Tool for Gemini to locate drinks."""
       goal = LocateDrink.Goal()
       goal.drinkname = drink_name

       future = self.locate_drink_client.send_goal_async(goal)
       # Handle result...
   ```

## Future Enhancements

Potential improvements:
- [ ] Object tracking to reduce API calls
- [ ] Multiple drink detection and selection
- [ ] Integration with MoveIt for arm reaching
- [ ] Visual servoing for finer positioning
- [ ] Obstacle avoidance during positioning
- [ ] Dynamic reconfiguration of parameters
- [ ] Support for different camera types/calibrations

## License

MIT License

## Author

Created for the Wilson autonomous robot project.

## References

- [ROS2 Actions Documentation](https://docs.ros.org/en/humble/Tutorials/Intermediate/Writing-an-Action-Server-Client/Py.html)
- [Google Gemini API](https://ai.google.dev/docs)
- [Wilson Robot Documentation](../README.md)

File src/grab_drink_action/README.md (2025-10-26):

# Grab Drink Action Server

A ROS2 action server for grabbing drinks using MoveIt Task Constructor.

## Overview

This package provides an action server that accepts grab requests with drink coordinates in the `depth_camera_link_optical` frame and executes a grab sequence using MoveIt Task Constructor.

## Action Interface

### Action Name
`grab_drink`

### Goal Message
```
float64 targetx                          # X-coordinate of drink (in depth_camera_link_optical frame)
float64 targety                          # Y-coordinate of drink (in depth_camera_link_optical frame)
float64 targetz                          # Z-coordinate of drink (in depth_camera_link_optical frame)
```

**Notes:**
- All coordinates are in the `depth_camera_link_optical` frame
- Drink dimensions are hardcoded (height: 0.122m, radius: 0.033m for standard can size)

### Feedback Message
```
string current_stage                     # Current execution stage
float32 progress_percentage              # Progress (0-100%)
```

### Result Message
```
bool success                             # Whether the grab succeeded
string message                           # Status/error message
geometry_msgs/Pose final_drink_pose      # Final drink pose in world frame
```

## Building

```bash
cd ~/wilson
colcon build --packages-select grab_drink_action
source install/setup.bash
```

## Usage

### Launch the Action Server

```bash
ros2 launch grab_drink_action grab_drink_server.launch.py
```

### Send a Goal via Command Line

```bash
# Basic example - grab drink at x=0, y=0.1, z=0.65 in depth_camera_link_optical frame
ros2 action send_goal /grab_drink grab_drink_action/action/GrabDrink "{
  targetx: 0.0,
  targety: 0.09,
  targetz: 0.65
}" --feedback
```

### Send a Goal from Python

```python
import rclpy
from rclpy.action import ActionClient
from rclpy.node import Node
from grab_drink_action.action import GrabDrink
from geometry_msgs.msg import Point

class GrabDrinkClient(Node):
    def __init__(self):
        super().__init__('grab_drink_client')
        self._action_client = ActionClient(self, GrabDrink, 'grab_drink')

    def send_goal(self, x, y, z):
        goal_msg = GrabDrink.Goal()
        goal_msg.targetx = x
        goal_msg.targety = y
        goal_msg.targetz = z

        self._action_client.wait_for_server()

        send_goal_future = self._action_client.send_goal_async(
            goal_msg,
            feedback_callback=self.feedback_callback
        )
        send_goal_future.add_done_callback(self.goal_response_callback)

    def goal_response_callback(self, future):
        goal_handle = future.result()
        if not goal_handle.accepted:
            self.get_logger().info('Goal rejected')
            return

        self.get_logger().info('Goal accepted')
        result_future = goal_handle.get_result_async()
        result_future.add_done_callback(self.result_callback)

    def feedback_callback(self, feedback_msg):
        feedback = feedback_msg.feedback
        self.get_logger().info(f'Stage: {feedback.current_stage}, Progress: {feedback.progress_percentage}%')

    def result_callback(self, future):
        result = future.result().result
        if result.success:
            self.get_logger().info(f'Success! {result.message}')
        else:
            self.get_logger().error(f'Failed: {result.message}')

def main(args=None):
    rclpy.init(args=args)
    client = GrabDrinkClient()

    # Example: Grab drink at position relative to depth camera
    client.send_goal(x=0.45, y=-0.07, z=0.1, frame='depth_camera_link_optical')

    rclpy.spin(client)

if __name__ == '__main__':
    main()
```

## Features

- **Dynamic Frame Transformation**: Automatically transforms target coordinates from the specified frame to the world frame
- **Standard Drink Dimensions**: Uses hardcoded dimensions optimized for standard can size (height: 0.122m, radius: 0.033m)
- **Progress Feedback**: Provides real-time feedback on execution progress
- **Dynamic Approach Vector**: Computes approach direction based on robot base position
- **Full Grab Sequence**: Executes complete grab sequence including:
  - Open gripper
  - Move to pre-grasp position
  - Approach drink
  - Generate grasp pose
  - Close gripper
  - Attach drink
  - Lift drink
  - Return home

## Configuration

The action server uses the following MoveIt group names (defined in the source code):
- **arm_group**: `"arm"`
- **hand_group**: `"gripper"`
- **hand_frame**: `"end_effector_frame"`

To change these, modify the constants in [src/grab_drink_action_server.cpp](src/grab_drink_action_server.cpp:334-336).

## Troubleshooting

### Action server not available
Make sure the action server is running and MoveIt is properly configured:
```bash
ros2 action list
# Should show: /grab_drink
```

### Transform errors
Ensure all required TF frames are being published:
```bash
ros2 run tf2_ros tf2_echo base_link depth_camera_link_optical
```

### Planning failures
Check that:
1. The target position is reachable
2. MoveIt is properly configured for your robot
3. Collision checking is not too restrictive

## Dependencies

- `rclcpp`
- `rclcpp_action`
- `moveit_task_constructor_core`
- `tf2_ros`
- `geometry_msgs`
- `shape_msgs`

## License

TODO: Add license information

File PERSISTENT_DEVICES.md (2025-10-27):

# Persistent Device Names for Wilson Robot

## Problem

Every time the Raspberry Pi restarts, USB device addresses (`/dev/ttyUSB0`, `/dev/ttyUSB1`, `/dev/video8`, etc.) can change order, causing the robot to fail to start because devices are assigned to the wrong hardware.

## Solution

We use **udev rules** to create persistent symlinks in `/dev/wilson/` that always point to the correct device regardless of connection order.

## Device Mapping

| Device | Persistent Name | Description |
|---|---|---|
| LiDAR LD19 | `/dev/wilson/lidar` | CP2102 USB-UART Bridge (Silicon Labs) |
| Differential Drive Arduino | `/dev/wilson/diffdrive` | CH340 on USB3 Bus Port 1 |
| Arm Controller Arduino | `/dev/wilson/arm` | CH340 on USB1 Bus via hub at port 1.4 |
| RGB USB Camera | `/dev/wilson/rgb_camera` | HD USB Camera (32e4:9310) |
| CSI Camera (optional) | `/dev/wilson/csi_camera0` | Raspberry Pi CSI camera |

## Installation

### One-Time Setup

Run the installation script as root:

```bash
cd /home/pi5/wilson
sudo ./install_udev_rules.sh
```

The script will:
1. Copy the udev rules to `/etc/udev/rules.d/`
2. Reload udev rules
3. Trigger device detection
4. Verify all persistent device names are created

### Manual Installation

If you prefer to install manually:

```bash
sudo cp 99-wilson-robot.rules /etc/udev/rules.d/
sudo udevadm control --reload-rules
sudo udevadm trigger
```

### Verification

Check that all device symlinks exist:

```bash
ls -la /dev/wilson/
```

You should see:
```
lrwxrwxrwx  1 root root  10 Oct 26 22:00 arm -> ../ttyUSB2
lrwxrwxrwx  1 root root    9 Oct 26 22:00 csi_camera0 -> ../video2
lrwxrwxrwx  1 root root   10 Oct 26 22:00 diffdrive -> ../ttyUSB1
lrwxrwxrwx  1 root root   10 Oct 26 22:00 lidar -> ../ttyUSB0
lrwxrwxrwx  1 root root    9 Oct 26 22:00 rgb_camera -> ../video0
```

The actual target devices (`ttyUSBX`, `videoX`) may vary, but the symlinks will always be correct.

## Updated Files

The following files have been updated to use persistent device names:

### Launch Files
- [src/ldlidar_stl_ros/launch/ld19.launch.py](src/ldlidar_stl_ros/launch/ld19.launch.py) - Uses `/dev/wilson/lidar`
- [src/wilson/launch/real/cameras_and_locate.launch.py](src/wilson/launch/real/cameras_and_locate.launch.py) - Uses `/dev/wilson/rgb_camera`
- [src/wilson/launch/real/robot.launch.py](src/wilson/launch/real/robot.launch.py) - Uses `/dev/wilson/rgb_camera`

### Hardware Configuration
- [src/wilson/ros2_control/wilson_system.ros2_control.xacro](src/wilson/ros2_control/wilson_system.ros2_control.xacro) - Uses `/dev/wilson/diffdrive` and `/dev/wilson/arm`

## How It Works

### Udev Rules Matching

The udev rules use the following attributes to uniquely identify each device:

1. **LiDAR**: Matches by USB Vendor/Product ID (10c4:ea60 - Silicon Labs CP2102)
2. **Differential Drive**: Matches by Vendor/Product ID (1a86:7523) AND USB bus path (usb3/3-1)
3. **Arm Controller**: Matches by Vendor/Product ID (1a86:7523) AND USB bus path (usb1/1-1/1-1.4)
4. **RGB Camera**: Matches by USB Vendor/Product ID (32e4:9310)

### Why Device Paths?

The differential drive and arm controller both use the same CH340 USB-serial chip (idVendor=1a86, idProduct=7523), so we differentiate them by their physical USB port location:
- **Diffdrive** is plugged into USB3 bus, port 1 (standalone port)
- **Arm** is plugged into USB1 bus, through a hub at port 1, subport 4

This means as long as you keep the devices plugged into the same physical USB ports, they will always get the correct persistent name.

## Troubleshooting

### Device Not Creating Symlink

If a device doesn't appear in `/dev/wilson/`:

1. **Check device is connected:**
   ```bash
   lsusb
   ls -la /dev/ttyUSB* /dev/video*
   ```

2. **Check device attributes:**
   ```bash
   udevadm info -a -n /dev/ttyUSB0  # Replace with your device
   ```

3. **Test udev rule matching:**
   ```bash
   udevadm test /sys/class/tty/ttyUSB0  # Replace with your device
   ```

4. **Check kernel messages:**
   ```bash
   dmesg | tail -20
   ```

### Device Moved to Different USB Port

If you physically move a device to a different USB port:

1. Find the new device path:
   ```bash
   udevadm info -a -n /dev/ttyUSBX | grep DEVPATH
   ```

2. Update the corresponding line in `99-wilson-robot.rules`

3. Reinstall the rules:
   ```bash
   sudo ./install_udev_rules.sh
   ```

### Verify Rule is Working

To test if a specific device matches the rule:

```bash
# For serial devices
udevadm test /sys/class/tty/ttyUSB0 2>&1 | grep wilson

# For video devices
udevadm test /sys/class/video4linux/video0 2>&1 | grep wilson
```

You should see lines indicating the symlink creation.

## Depth Camera Note

The ArducamDepthCamera is accessed via its Python library (ArducamDepthCamera) and does NOT use a `/dev/video` device, so no udev rule is needed for it.

## Benefits

1. **Reliability**: Robot will start correctly after reboot regardless of USB enumeration order
2. **Clarity**: Device names like `/dev/wilson/arm` are more readable than `/dev/ttyUSB2`
3. **Debugging**: Easy to verify which device is which with `ls -la /dev/wilson/`
4. **Robustness**: Survives USB hot-plugging and reconnection

## Testing After Reboot

To verify the persistent names survive a reboot:

```bash
# Before reboot, note which ttyUSBX devices map to which symlinks
ls -la /dev/wilson/

# Reboot
sudo reboot

# After reboot, check again
ls -la /dev/wilson/
```

The symlinks should still point to the correct hardware, even if the underlying `ttyUSBX` numbers changed.

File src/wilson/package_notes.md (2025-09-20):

in bashrc paste
export GAZEBO_MODEL_PATH=/home/trace/wilson/install/wilson/share/wilson/worlds:$GAZEBO_MODEL_PATH

Created low fidelity collision mesh models. 

Make sure all links have mass/inertia or gazebo will ignore.

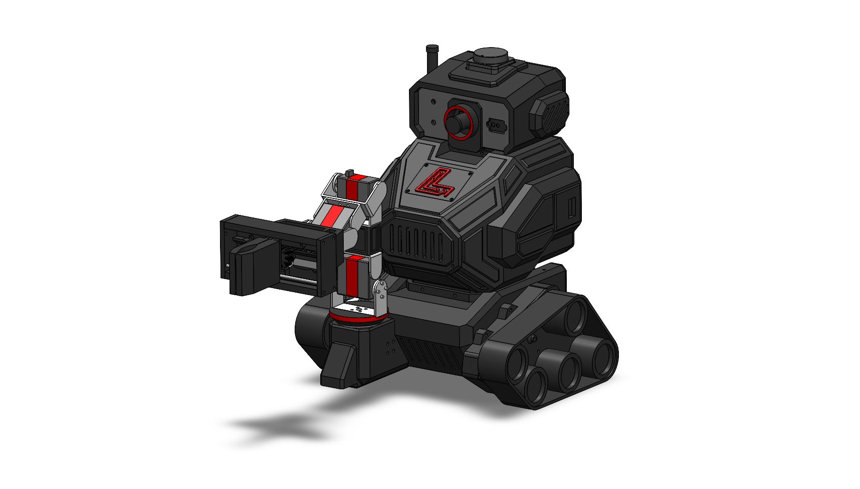
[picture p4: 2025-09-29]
pictures/wilson_solidworks_white_backgorund.JPG

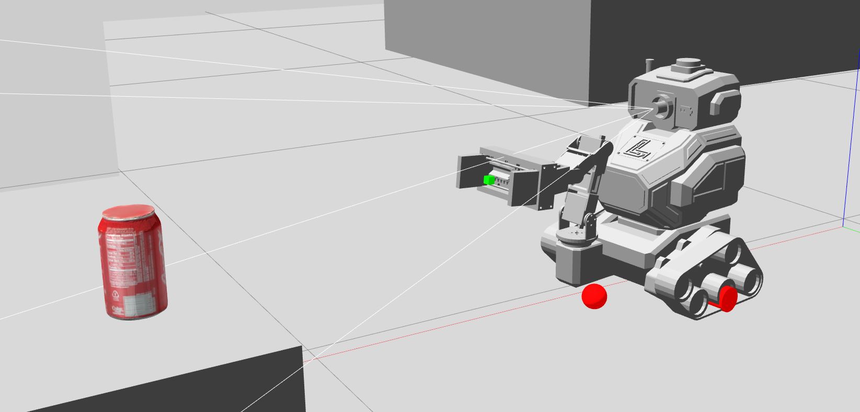
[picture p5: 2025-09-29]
pictures/gazebo_sim.JPG

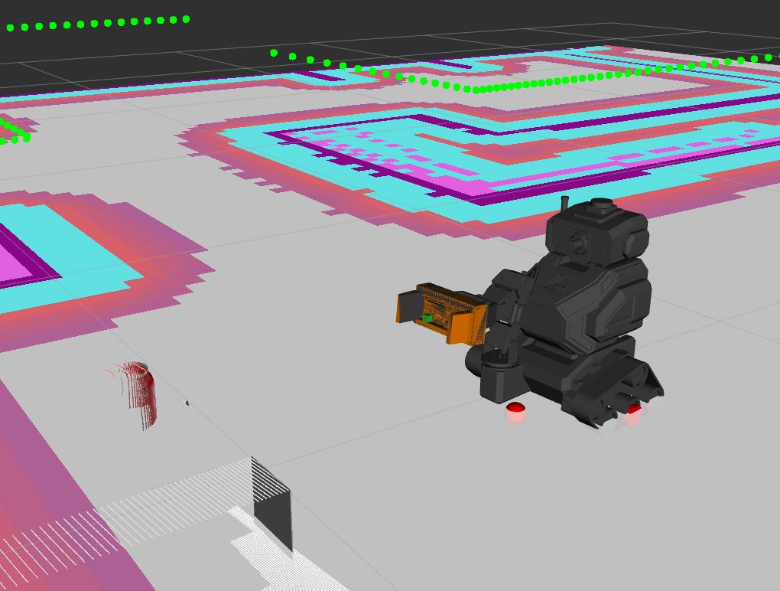
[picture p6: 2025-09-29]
pictures/Rviz_screenshot.JPG

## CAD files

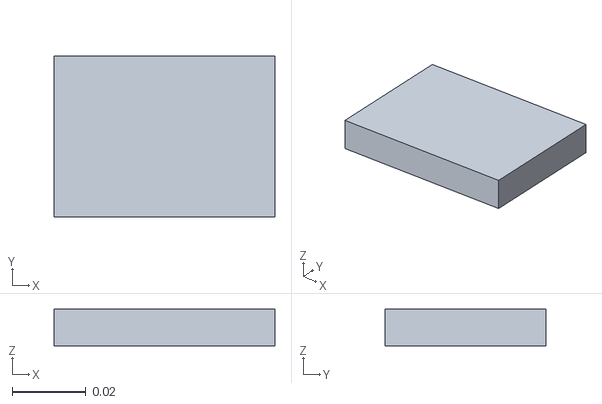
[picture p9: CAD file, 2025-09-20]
src/wilson/collision_meshes/gripper_right_finger.STL
0.06 x 0.0437 x 0.01

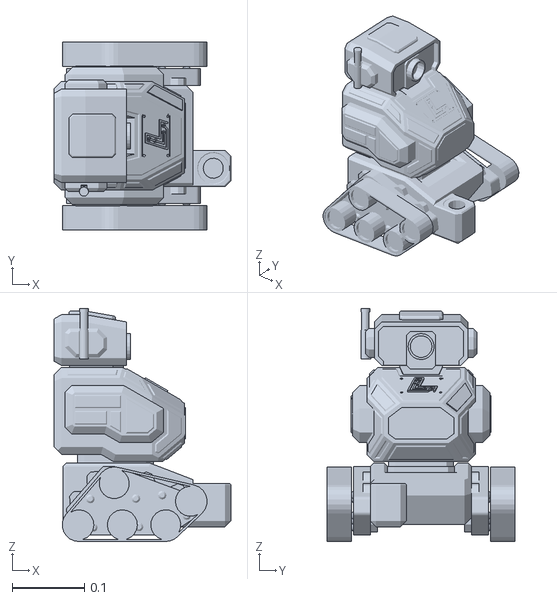
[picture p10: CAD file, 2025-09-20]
src/wilson/meshes/body_link.STL
0.244 x 0.26 x 0.322

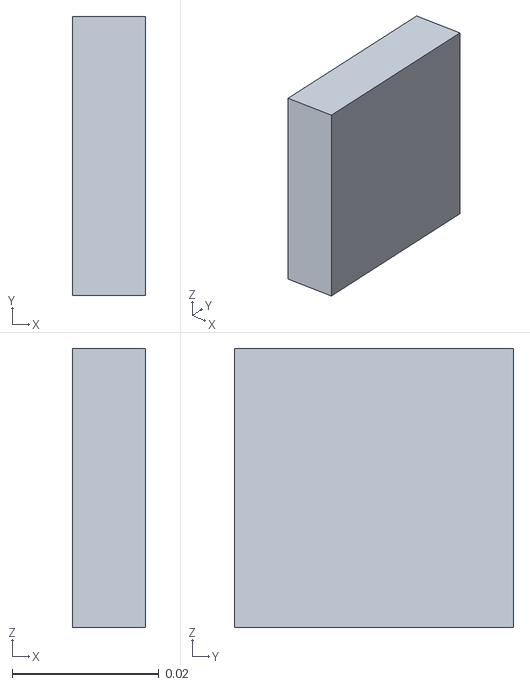
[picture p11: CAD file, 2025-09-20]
src/wilson/collision_meshes/camera_link.STL
0.01 x 0.038 x 0.038

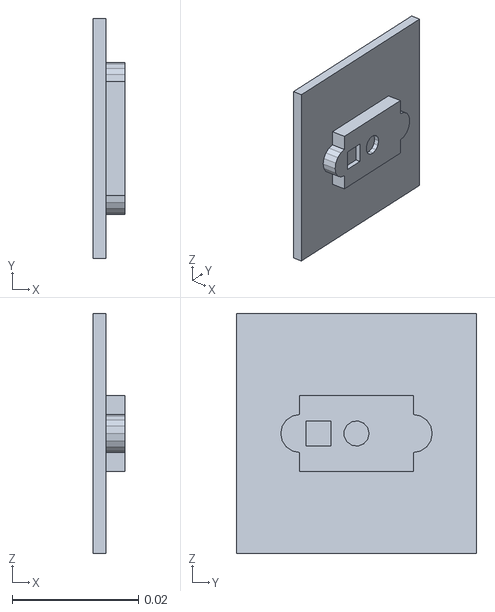
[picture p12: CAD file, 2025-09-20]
src/wilson/meshes/depth_camera_link.STL
0.005 x 0.038 x 0.038

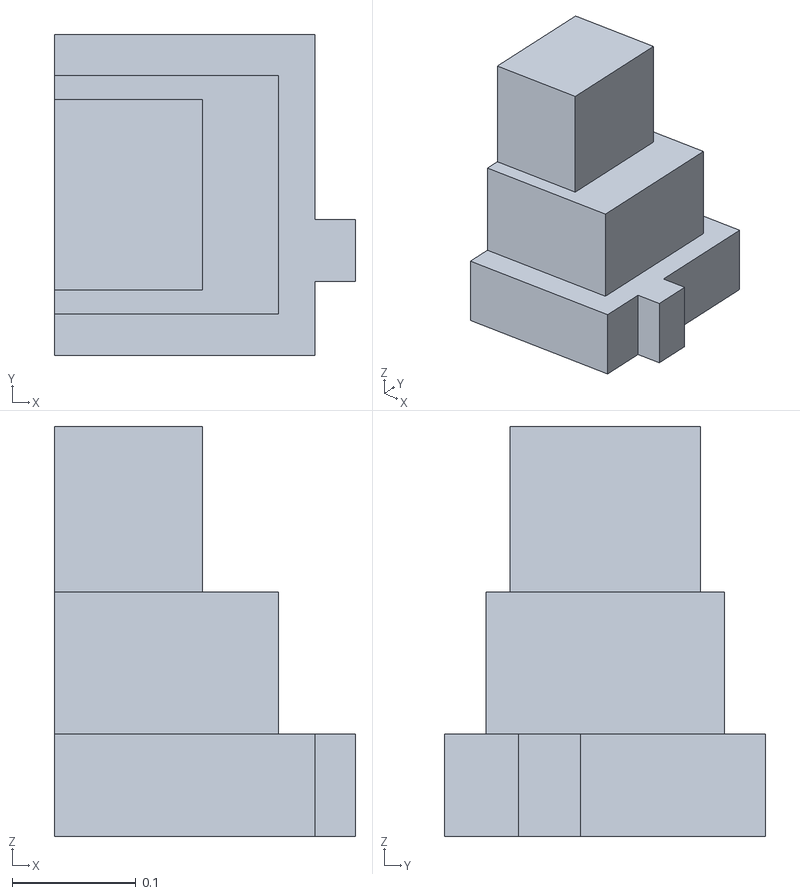
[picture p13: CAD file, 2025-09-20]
src/wilson/collision_meshes/body_link.STL
0.244 x 0.26 x 0.332

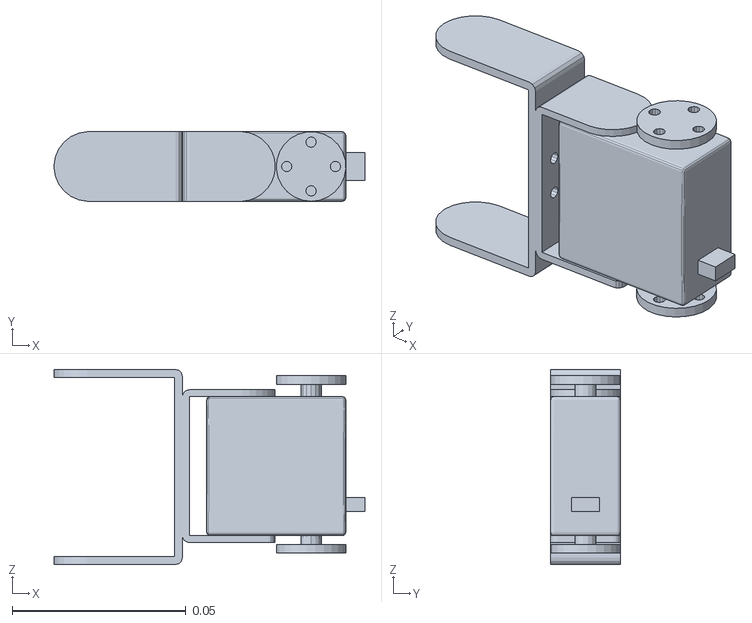
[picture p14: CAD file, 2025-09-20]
src/wilson/meshes/link_3.STL
0.0894 x 0.02 x 0.0561

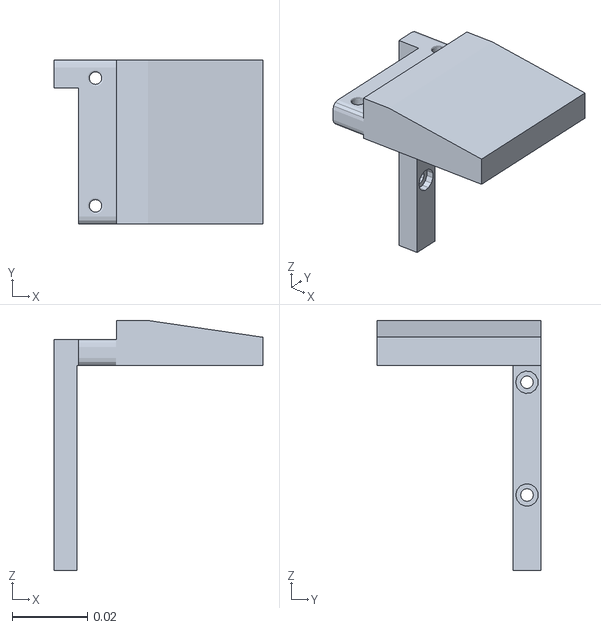
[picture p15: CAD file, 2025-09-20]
src/wilson/meshes/gripper_left_finger.STL
0.0555 x 0.0437 x 0.0665

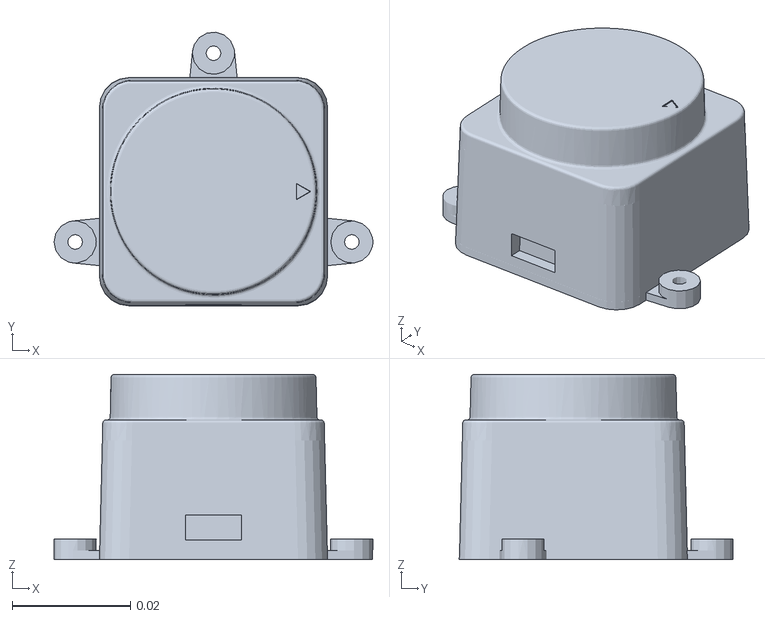
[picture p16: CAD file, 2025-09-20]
src/wilson/meshes/laser_frame.STL
0.054 x 0.0463 x 0.0313

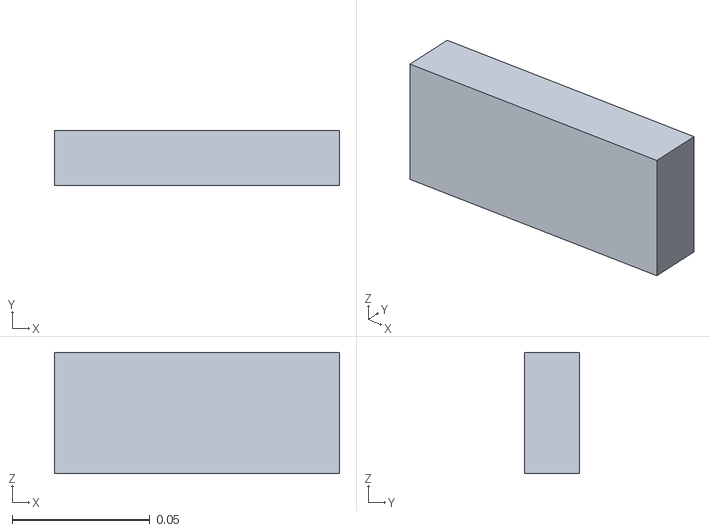
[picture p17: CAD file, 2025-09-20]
src/wilson/collision_meshes/link_2.STL
0.104 x 0.02 x 0.044

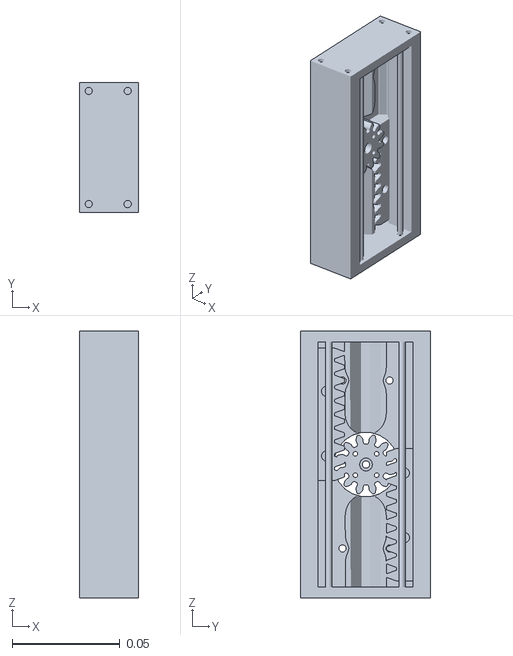
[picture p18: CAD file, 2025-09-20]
src/wilson/meshes/gripper_base.STL
0.0272 x 0.0603 x 0.124

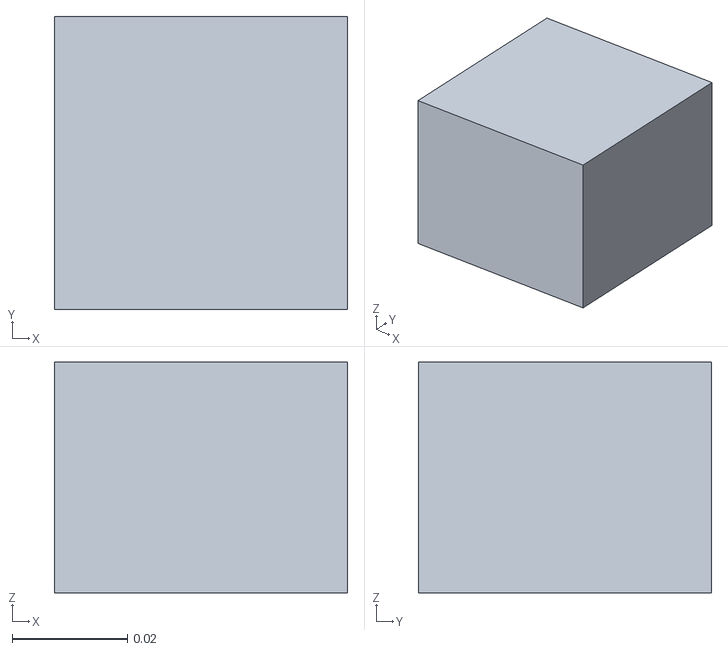
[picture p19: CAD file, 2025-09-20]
src/wilson/collision_meshes/link_1.STL
0.0508 x 0.0508 x 0.04

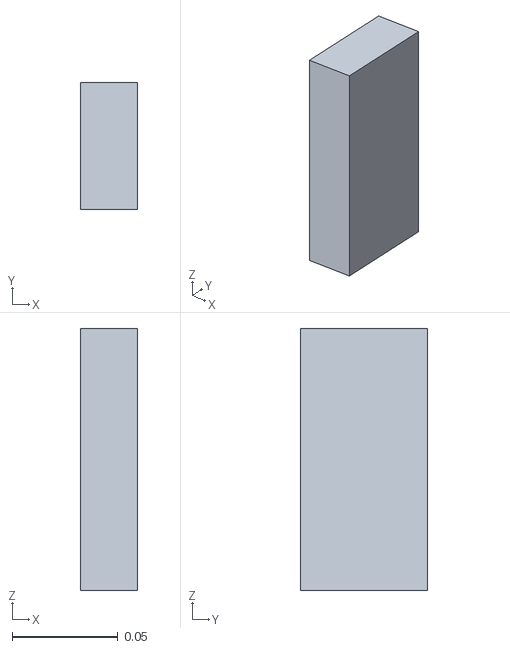
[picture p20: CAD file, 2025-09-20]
src/wilson/collision_meshes/gripper_base.STL
0.0272 x 0.0603 x 0.124

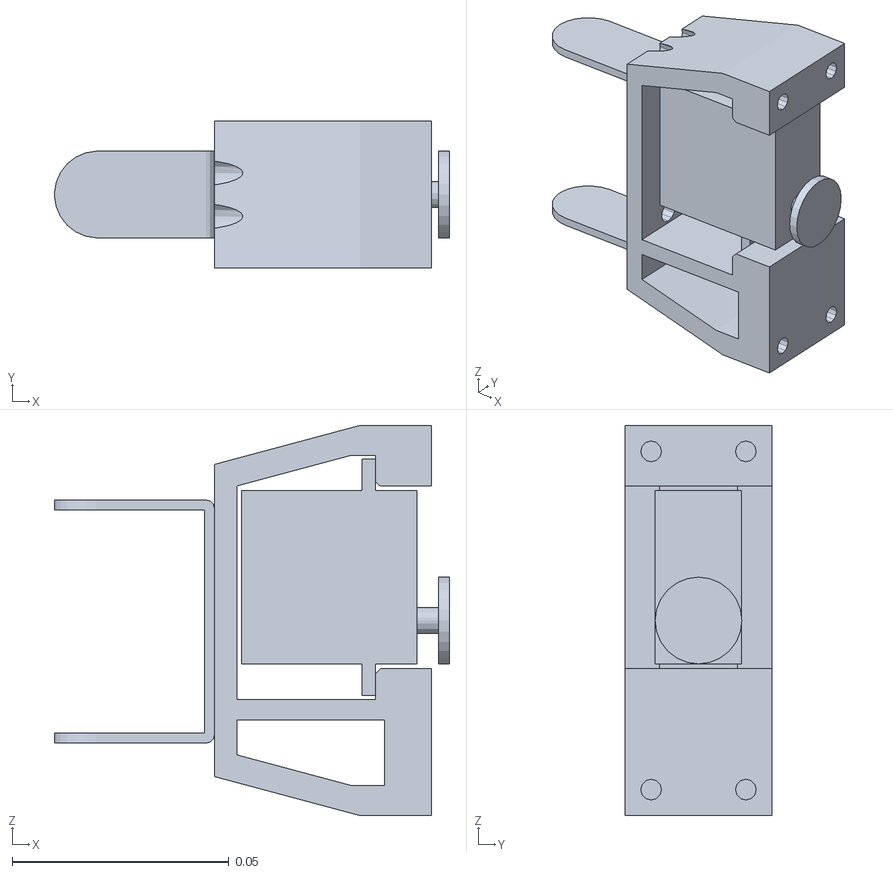
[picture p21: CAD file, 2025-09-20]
src/wilson/meshes/link_4.STL
0.0911 x 0.0339 x 0.09

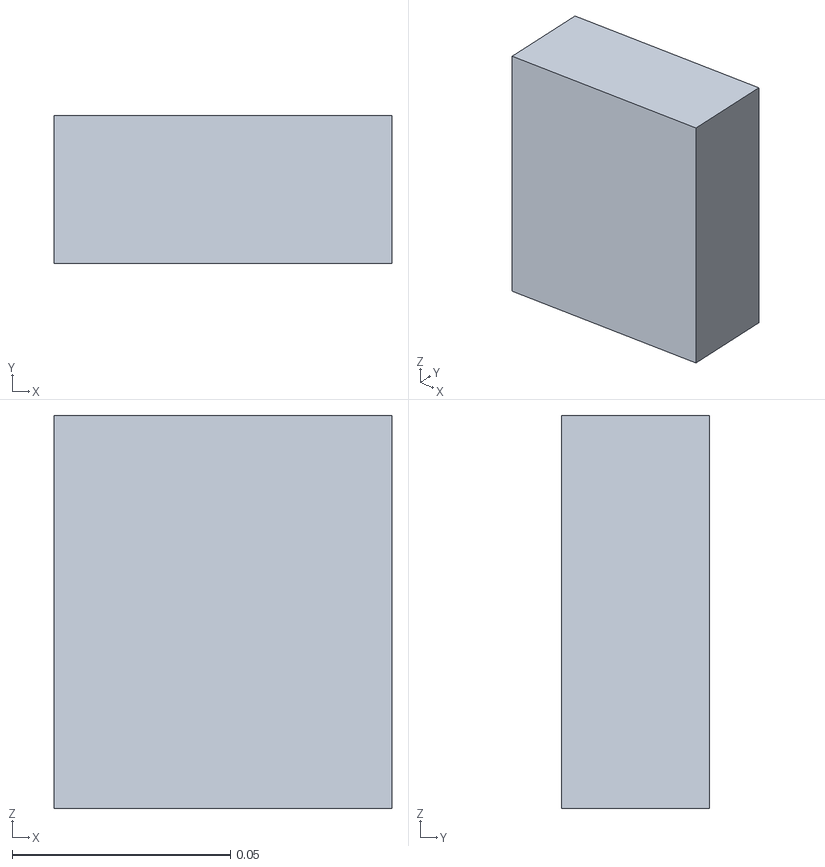
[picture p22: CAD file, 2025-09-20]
src/wilson/collision_meshes/link_4.STL
0.0773 x 0.0339 x 0.09

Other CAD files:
src/wilson/collision_meshes/gripper_left_finger.STL
src/wilson/collision_meshes/laser_frame.STL
src/wilson/meshes/gripper_right_finger.STL
src/wilson/meshes/camera_link.STL
src/wilson/collision_meshes/depth_camera_link.STL
src/wilson/collision_meshes/link_3.STL
src/wilson/meshes/link_1.STL
src/wilson/meshes/link_2.STL

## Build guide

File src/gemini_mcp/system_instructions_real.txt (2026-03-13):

Start by connecting to the robot on ip 192.168.8.175, port 9090.
Then use get_action_details on /locate_object, /grab_object, and /move_to_state.
Once done, end your turn and reply only with "Successfully connected."

You are free to engage in conversation with the user outside of robotics as well. 

When using send_action_goal, use a timeout of 180 seconds.

You can move the arm and gripper to the following states using /move_to_state:
- ready
- idle
- zero
- ready_to_grab
- ground_grab
- air_grab
- open
- close
- can

When simply asked to just grab an object, use send_action_goal to /grab_object with the following goal:
{targetx: 0.0,
targety: 0.07, 
targetz: 0.375}

You can use send_action_goal grab a requested object for the user. 
1. Say "Got it. I'll get the {object_name}". Use /locate_object to find the requested object and get its relative coordinates.
2. Say "I'm grabbing the {object_name}". Use the x, y, and z coordinates returned from /locate_object to use /grab_object to grab the requested object.
3. Now wait for user response. When the user says "thank you Wilson", use /move_to_state to open the gripper, then move to idle, then close the gripper.

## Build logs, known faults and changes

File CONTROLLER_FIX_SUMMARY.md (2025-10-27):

# Controller Issue Fix Summary

## Problem

The robot controllers were failing to spawn due to confusion with the `use_fake_hardware` parameter and URDF file selection in the launch system.

## Root Causes

1. **Invalid URDF Selection Logic**: The [rsp.launch.py](src/wilson/launch/base/rsp.launch.py) was using a `PythonExpression` substitution to dynamically choose between `wilson.urdf.xacro` and `wilson_real.urdf.xacro`, but this approach doesn't work correctly in ROS2 launch files because substitutions can't be used directly in file path selection.

2. **Camera Offset Confusion**: Changes were made to add conditional camera offsets in [wilson_core.xacro](src/wilson/urdf/wilson_core.xacro) based on `use_fake_hardware`, but the URDF selection logic was preventing this parameter from being passed correctly.

## Solution

### 1. Simplified URDF Selection

**Changed**: [src/wilson/launch/base/rsp.launch.py:29-36](src/wilson/launch/base/rsp.launch.py#L29-L36)

Instead of trying to dynamically select different URDF files, we now:
- Always use `wilson.urdf.xacro` as the main URDF
- Pass the `use_fake_hardware` parameter through to xacro
- Let the URDF conditionals handle hardware-specific configuration

**Before** (broken):
```python
from launch.substitutions import PythonExpression
xacro_file = PythonExpression([
    '"', os.path.join(pkg_path, 'urdf', 'wilson.urdf.xacro'), '" if "', use_fake_hardware, '" == "true" else "',
    os.path.join(pkg_path, 'urdf', 'wilson_real.urdf.xacro'), '"'
])
```

**After** (fixed):
```python
xacro_file = os.path.join(pkg_path, 'urdf', 'wilson.urdf.xacro')
robot_description_config = Command([
    'xacro ', xacro_file,
    ' use_sim_time:=', use_sim_time,
    ' use_fake_hardware:=', use_fake_hardware,
    ' use_ros2_control:=', use_ros2_control
])
```

### 2. Camera Offset Configuration

The camera offsets in [wilson_core.xacro](src/wilson/urdf/wilson_core.xacro) now correctly use conditional logic:

- **Simulation** (`use_fake_hardware=true`): Uses `-0.25 0 0` offset to work around Open3D clip distance issues
- **Real Robot** (`use_fake_hardware=false`): Uses `0 0 0` offset (no offset needed)

This applies to both:
- `camera_sensor_joint` (RGB camera)
- `depth_camera_sensor_joint` (Depth camera)

## How It Works Now

### Simulation Launch
```bash
ros2 launch wilson wilson_sim.launch.py
```
- Loads `wilson.urdf.xacro` with `use_fake_hardware=true`
- Uses Gazebo simulation hardware plugin
- Applies -0.25m camera offset for Open3D compatibility
- Controllers connect to simulated hardware

### Real Robot Launch
```bash
ros2 launch wilson wilson_real.launch.py
```
- Loads `wilson.urdf.xacro` with `use_fake_hardware=false` (set in [robot.launch.py:31](src/wilson/launch/real/robot.launch.py#L31))
- Uses real Arduino hardware interfaces:
  - `/dev/wilson/diffdrive` for differential drive
  - `/dev/wilson/arm` for arm controller
- No camera offset applied (cameras at true physical position)
- Controllers connect to real hardware via persistent device names

## Parameter Flow

1. **robot.launch.py** passes `use_fake_hardware: 'false'` to rsp.launch.py
2. **rsp.launch.py** passes it to xacro command
3. **wilson.urdf.xacro** receives the parameter and passes it to included files
4. **wilson_core.xacro** uses conditionals (`<xacro:if>` / `<xacro:unless>`) based on the parameter
5. **wilson_system.ros2_control.xacro** selects appropriate hardware plugins

## Configuration Files

### URDF Defaults
- [wilson.urdf.xacro:6](src/wilson/urdf/wilson.urdf.xacro#L6): `use_fake_hardware` default = `true` (for simulation)
- [wilson_core.xacro:8](src/wilson/urdf/wilson_core.xacro#L8): `use_fake_hardware` default = `false` (inherited from parent)

### Launch File Overrides
- [sim.launch.py](src/wilson/launch/sim/sim.launch.py): Uses sim_params.yaml which sets `use_fake_hardware: true`
- [robot.launch.py:31](src/wilson/launch/real/robot.launch.py#L31): Explicitly sets `use_fake_hardware: 'false'`

## Testing

To verify the fix is working:

### Test 1: Check URDF Processing
```bash
# From wilson directory, check that xacro processes correctly for real robot
xacro src/wilson/urdf/wilson.urdf.xacro use_fake_hardware:=false use_sim_time:=false use_ros2_control:=true > /tmp/real_robot.urdf

# Check camera offset is 0 (real robot)
grep -A 3 "camera_sensor_joint" /tmp/real_robot.urdf | grep xyz

# Check hardware interfaces point to persistent devices
grep -E "/dev/wilson/(diffdrive|arm)" /tmp/real_robot.urdf
```

### Test 2: Verify Controller Spawning
```bash
# In docker container, after launching the real robot:
ros2 control list_controllers

# Expected output:
# diff_drive_controller[diff_drive_controller/DiffDriveController] active
# arm_controller[joint_trajectory_controller/JointTrajectoryController] active
# gripper_controller[joint_trajectory_controller/JointTrajectoryController] active
# joint_state_broadcaster[joint_state_broadcaster/JointStateBroadcaster] active
```

### Test 3: Hardware Interface Check
```bash
# Check hardware interfaces loaded correctly
ros2 control list_hardware_interfaces

# Should see interfaces for:
# - left_wheel_joint and right_wheel_joint (velocity command, position/velocity state)
# - joint_1 through joint_4 (position command/state)
# - gripper joints (position command/state)
```

## Benefits

1. **Simplified Architecture**: Single URDF file with conditional logic is easier to maintain than multiple URDF files
2. **Correct Parameter Passing**: `use_fake_hardware` now flows correctly through the entire launch system
3. **Hardware Flexibility**: Same URDF works for both simulation and real robot
4. **Proper Camera Positioning**: Cameras are positioned correctly for both sim and real contexts

## Related Files

### Modified Files
- [src/wilson/launch/base/rsp.launch.py](src/wilson/launch/base/rsp.launch.py) - Simplified URDF selection
- [src/wilson/urdf/wilson_core.xacro](src/wilson/urdf/wilson_core.xacro) - Added conditional camera offsets
- [src/wilson/urdf/wilson.urdf.xacro](src/wilson/urdf/wilson.urdf.xacro) - Updated default for use_fake_hardware

### Unchanged (Working Correctly)
- [src/wilson/launch/real/robot.launch.py](src/wilson/launch/real/robot.launch.py) - Correctly passes use_fake_hardware=false
- [src/wilson/ros2_control/wilson_system.ros2_control.xacro](src/wilson/ros2_control/wilson_system.ros2_control.xacro) - Hardware plugin selection works correctly
- [src/wilson/config/robot_controller_manager.yaml](src/wilson/config/robot_controller_manager.yaml) - Controller configuration

## Troubleshooting

### Issue: Controllers fail to spawn
**Check**:
1. Verify `use_fake_hardware` is being set correctly in launch arguments
2. Check that the URDF generates without errors: `xacro <file> ... > /tmp/test.urdf`
3. Ensure hardware devices exist: `ls -la /dev/wilson/`

### Issue: "No such file /dev/ttyUSBX"
**Fix**: The persistent device names should handle this, but if you see this error it means:
1. The udev rules aren't installed or active
2. The hardware isn't plugged in
3. Run: `sudo ./install_udev_rules.sh` to reinstall

### Issue: Camera transforms are wrong
**Check**:
1. Verify which URDF is being used with `ros2 param get /robot_state_publisher robot_description`
2. Check `use_fake_hardware` parameter: Should be `false` for real robot, `true` for sim
3. View in RViz to visualize camera positions

## Next Steps

1. **Test in Docker Container**: Build and test the real robot launch to verify controllers spawn correctly
2. **Verify Hardware Communication**: Test that commands reach the Arduino controllers via persistent device names
3. **Validate Camera Frames**: Ensure camera TF frames are at correct physical positions

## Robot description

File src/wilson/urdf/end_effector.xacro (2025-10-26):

<?xml version="1.0"?>
<robot xmlns:xacro="http://www.ros.org/wiki/xacro" >

    <xacro:property name="end_effector_offset_x" value="0.06"/>
    <xacro:property name="green" value="0.2 0.8 0.2 1.0"/>

    <!-- End effector frame (for convenience in motion planning) -->
    <joint name="end_effector_roll_joint" type="revolute">
        <parent link="gripper_base"/>
        <child link="end_effector_roll"/>
        <origin xyz="${end_effector_offset_x} 0 0" rpy="0 0 0"/>
        <axis xyz="1 0 0"/>
        <limit effort="0.0" lower="-3.14" upper="3.14" velocity="1"/>
    </joint>

    <link name="end_effector_roll">
        <visual>
        <origin xyz="0 0 0" rpy="0 0 0"/>
        <geometry>
            <box size="0.01 0.01 0.01"/>
        </geometry>
        <material name="end_effector_roll_material">
            <color rgba="${green}"/>
        </material>
        </visual>
    </link>

    <joint name="end_effector_yaw_joint" type="revolute">
        <parent link="end_effector_roll"/>
        <child link="end_effector_yaw"/>
        <origin xyz="0 0 0" rpy="0 0 0"/>
        <axis xyz="0 0 1"/>
        <limit effort="0.0" lower="-3.14" upper="3.14" velocity="1"/>
    </joint>
    <link name="end_effector_yaw">
        <visual>
        <origin xyz="0 0 0" rpy="0 0 0"/>
        <geometry>
            <box size="0.01 0.01 0.01"/>
        </geometry>
        <material name="end_effector_yaw_material">
            <color rgba="${green}"/>
        </material>
        </visual>
    </link>

    <!-- End effector frame -->
    <joint name="end_effector_joint" type="fixed">
        <parent link="end_effector_yaw"/>
        <child link="end_effector_frame"/>
        <origin xyz="0 0 0" rpy="0 0 0"/>
    </joint>

    <link name="end_effector_frame">
        <visual>
        <origin xyz="0 0 0" rpy="0 0 0"/>
        <geometry>
            <box size="0.01 0.01 0.01"/>
        </geometry>
        <material name="end_effector_roll_material">
            <color rgba="${green}"/>
        </material>
        </visual>
    </link>

    <gazebo reference="end_effector_roll">
        <material>Gazebo/Green</material>
    </gazebo>

    <gazebo reference="end_effector_yaw">
        <material>Gazebo/Green</material>
    </gazebo>

    <!-- End effector frame material -->
    <gazebo reference="end_effector_frame">
        <material>Gazebo/Green</material>
    </gazebo>

</robot>

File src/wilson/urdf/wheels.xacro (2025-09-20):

<?xml version="1.0"?>
<robot xmlns:xacro="http://www.ros.org/wiki/xacro" >

    <xacro:include filename="inertial_macros.xacro"/> 

    <material name="white">
        <color rgba="1 1 1 1"/>
    </material>

    <material name="black">
        <color rgba="0 0 0 1"/>
    </material>

    <material name="red">
        <color rgba="1 0 0 1"/>
    </material>

    <material name="green">
        <color rgba="0 1 0 1"/>
    </material>

    <material name="blue">
        <color rgba="0 0 1 1"/>
    </material>

    <!-- BASE_FOOTPRINT LINK -->
    <joint name="base_footprint_joint" type="fixed">
        <parent link="base_link"/>
        <child link="base_footprint"/>
        <origin xyz="0 0 0" rpy="0 0 0"/>
    </joint>

    <link name="base_footprint">
    </link>

    <!-- LEFT WHEEL LINK -->

    <joint name="left_wheel_joint" type="continuous">
        <parent link="body_link"/>
        <child link="left_wheel"/>
        <origin xyz="0.075 0.1175 -.01" rpy="-${pi/2} 0 0" />
        <axis xyz="0 0 1"/>
    </joint>

    <link name="left_wheel">
        <visual>
            <geometry>
                <cylinder radius="0.018" length="0.03"/>
            </geometry>
            <material name="red"/>
        </visual>
        <collision>
            <geometry>
                <cylinder radius="0.018" length="0.03"/>
            </geometry>
        </collision>
        <xacro:inertial_cylinder mass="0.1" length="0.03" radius="0.018">
            <origin xyz="0 0 0" rpy="0 0 0"/>
        </xacro:inertial_cylinder>
    </link>

    <gazebo reference="left_wheel">
        <material>Gazebo/Red</material>
    </gazebo>

    <!-- RIGHT WHEEL LINK -->

    <joint name="right_wheel_joint" type="continuous">
        <parent link="body_link"/>
        <child link="right_wheel"/>
        <origin xyz="0.075 -0.1175 -.01" rpy="${pi/2} 0 0" />
        <axis xyz="0 0 -1"/>
    </joint>

    <link name="right_wheel">
        <visual>
            <geometry>
                <cylinder radius="0.018" length="0.03"/>
            </geometry>
            <material name="red"/>
        </visual>
        <collision>
            <geometry>
                <cylinder radius="0.018" length="0.03"/>
            </geometry>
        </collision>
        <xacro:inertial_cylinder mass="0.1" length="0.03" radius="0.018">
            <origin xyz="0 0 0" rpy="0 0 0"/>
        </xacro:inertial_cylinder>
    </link>

    <gazebo reference="right_wheel">
        <material>Gazebo/Red</material>
    </gazebo>

    <!-- FRONT CASTER WHEEL LINK -->

    <joint name="front_caster_wheel_joint" type="fixed">
        <parent link="body_link"/>
        <child link="front_caster_wheel"/>
        <origin xyz=".21 0.0 -0.01"/>
    </joint>
    
    <link name="front_caster_wheel">
        <visual>
            <geometry>
                <sphere radius="0.018"/>
            </geometry>
            <material name="red"/>
        </visual>
        <collision>
            <geometry>
                <sphere radius="0.018"/>
            </geometry>
        </collision>
        <xacro:inertial_sphere mass="0.1" radius="0.018">
            <origin xyz="0 0 0" rpy="0 0 0"/>
        </xacro:inertial_sphere>
    </link>

    <gazebo reference="front_caster_wheel">
        <material>Gazebo/Red</material>
        <mu1 value=".001"/>
        <mu2 value=".001"/>
    </gazebo>

    <!-- REAR CASTER WHEEL LINK -->

    <joint name="rear_caster_wheel_joint" type="fixed">
        <parent link="body_link"/>
        <child link="rear_caster_wheel"/>
        <origin xyz="0.0 0.0 -0.01"/>
    </joint>
    
    <link name="rear_caster_wheel">
        <visual>
            <geometry>
                <sphere radius="0.018"/>
            </geometry>
            <material name="red"/>
        </visual>
        <collision>
            <geometry>
                <sphere radius="0.018"/>
            </geometry>
        </collision>
        <xacro:inertial_sphere mass="0.1" radius="0.018">
            <origin xyz="0 0 0" rpy="0 0 0"/>
        </xacro:inertial_sphere>
    </link>

    <gazebo reference="rear_caster_wheel">
        <material>Gazebo/Red</material>
        <mu1 value=".001"/>
        <mu2 value=".001"/>
    </gazebo>

</robot>

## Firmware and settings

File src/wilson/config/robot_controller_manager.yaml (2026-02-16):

# Hardware configuration for Wilson robot

controller_manager:
  ros__parameters:
    use_sim_time: false
    update_rate: 100  # Hz

    joint_state_broadcaster:
      type: joint_state_broadcaster/JointStateBroadcaster

    arm_controller:
      type: joint_trajectory_controller/JointTrajectoryController

    gripper_controller:
      type: joint_trajectory_controller/JointTrajectoryController

    diff_drive_controller:
      type: diff_drive_controller/DiffDriveController



arm_controller:
  ros__parameters:
    use_sim_time: false
    joints:
      - joint_1
      - joint_2
      - joint_3
      - joint_4
      - end_effector_roll_joint
      - end_effector_yaw_joint
    interface_name: position
    
    command_interfaces:
      - position

    state_interfaces:
      - position

    open_loop: true
    allow_integration_in_goal_trajectories: true


gripper_controller:
  ros__parameters:
    use_sim_time: false
    joints:
      - gripper_left_finger_joint
      - gripper_right_finger_joint
    interface_name: position
    
    command_interfaces:
      - position

    state_interfaces:
      - position

    open_loop: true
    allow_integration_in_goal_trajectories: true

diff_drive_controller:
  ros__parameters:
    use_sim_time: false

    publish_rate: 50.0

    base_frame_id: base_link

    left_wheel_names: ['left_wheel_joint']
    right_wheel_names: ['right_wheel_joint']
    wheel_separation: 0.245
    wheel_radius: 0.018

    use_stamped_vel: false
    open_loop: true
    enable_odom_tf: true

    cmd_vel_timeout: 0.3

    # Velocity and acceleration limits
    linear.x.has_velocity_limits: true
    linear.x.has_acceleration_limits: true
    linear.x.max_velocity: 1.0
    linear.x.min_velocity: -1.0
    linear.x.max_acceleration: 100.0
    linear.x.min_acceleration: -100.0

    angular.z.has_velocity_limits: true
    angular.z.has_acceleration_limits: true
    angular.z.max_velocity: 1.0
    angular.z.min_velocity: -1.0
    angular.z.max_acceleration: 100.0
    angular.z.min_acceleration: -100.0

joint_state_broadcaster:
  ros__parameters:
    use_sim_time: false

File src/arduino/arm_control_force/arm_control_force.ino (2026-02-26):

#include <Servo.h>
#include <Wire.h>
#include <MLX90393.h>

Servo baseServo, shoulderServo, elbowServo, wristServo, gripperServo;

#define MIN_PULSE_WIDTH 500
#define MAX_PULSE_WIDTH 2500
#define SERVO_PHYSICAL_ANGLE 270
#define MAX_USER_ANGLE 270

// Serial buffer
String inputBuffer = "";

// Current servo positions (tracking) - matches ROS2 "idle" state from SRDF
int currentBase = 135, currentShoulder = 149, currentElbow = 10, currentWrist = 85, currentGripper = 0;
unsigned long lastCmdMs = 0;
bool servosAttached = true;
#define SERVO_IDLE_TIMEOUT_MS 500

// LED breathing variables
#define LED_PIN 11
int ledBrightness = 25;
int ledDirection = 1;
unsigned long lastLedUpdate = 0;
#define LED_UPDATE_INTERVAL 5  // Match arm_control timing

// MLX90393 sensor variables
MLX90393 mlx;
MLX90393 mlx_ambient;
MLX90393::txyz data;
MLX90393::txyz data_ambient;
MLX90393::txyzRaw raw_data;
MLX90393::txyzRaw raw_data_ambient;

// MLX sensor configuration
// NOTE: Higher OSR/DIG_FILT increases conversion time significantly.
int GAIN = 0;
int RES_X = 0;
int RES_Y = 0;
int RES_Z = 0;
int OSR = 2;       // fastest
int DIG_FILT = 4;  // fastest
int taredZ = 0;
int taredZAmbient = 0;

// Ambient MLX sensor uses a custom I2C address configured on-device.
// Update this value if the ambient sensor is programmed to a different address.
#define MLX_AMBIENT_ADDR 1
bool ambient_mlx_ready = true;

// MLX sensor timing
unsigned long lastMLXUpdate = 0;
#define MLX_UPDATE_INTERVAL 20  // Read every 20ms
bool mlx_inflight = false;
unsigned long mlx_start_ms = 0;
uint16_t mlx_conv_ms = 0;
const uint8_t mlx_flags = MLX90393::X_FLAG | MLX90393::Y_FLAG | MLX90393::Z_FLAG;

void setup() {
  Serial.begin(115200);

  // Initialize MLX sensor
  Wire.begin();
  // Raise I2C clock to improve MLX read throughput (default is 100kHz).
  Wire.setClock(400000);
  delay(50);
  mlx.begin();
  delay(50);
  mlx.setGainSel(GAIN);
  mlx.setResolution(RES_X, RES_Y, RES_Z);
  mlx.setOverSampling(OSR);
  mlx.setDigitalFiltering(DIG_FILT);

  // Initialize ambient MLX sensor at custom I2C address.
  mlx_ambient.begin(0, MLX_AMBIENT_ADDR, -1, Wire);
  mlx_ambient.setGainSel(GAIN);
  mlx_ambient.setResolution(RES_X, RES_Y, RES_Z);
  mlx_ambient.setOverSampling(OSR);
  mlx_ambient.setDigitalFiltering(DIG_FILT);

  mlx_conv_ms = mlx.convDelayMillis();

  // Setup LED pin
  pinMode(LED_PIN, OUTPUT);

  baseServo.attach(3, MIN_PULSE_WIDTH, MAX_PULSE_WIDTH);
  shoulderServo.attach(5, MIN_PULSE_WIDTH, MAX_PULSE_WIDTH);
  elbowServo.attach(6, MIN_PULSE_WIDTH, MAX_PULSE_WIDTH);
  wristServo.attach(9, MIN_PULSE_WIDTH, MAX_PULSE_WIDTH);
  gripperServo.attach(10, MIN_PULSE_WIDTH, MAX_PULSE_WIDTH);
  servosAttached = true;
  lastCmdMs = millis();

  // Default positions - matches ROS2 "idle" state {0.0, 0.2495, -2.1817, -0.6098, 0.0}
  setServoPosition(baseServo, 135);     // joint_1: 0.0 rad
  setServoPosition(shoulderServo, 149); // joint_2: 0.2495 rad (14.3°)
  setServoPosition(elbowServo, 10);     // joint_3: -2.1817 rad (-125°)
  setServoPosition(wristServo, 100);    // joint_4: -0.6098 rad (-34.9°)
  setServoPosition(gripperServo, 0);    // gripper: 0.0 rad

  Serial.println("ArduinoBot Servo Controller Ready (Direct Mode)");
}

void loop() {
  // Handle incoming servo commands (match arm_control loop ordering)
  while (Serial.available() > 0) {
    char incomingChar = Serial.read();

    if (incomingChar == ',') {
      processCommand(inputBuffer);
      inputBuffer = "";
    } else {
      inputBuffer += incomingChar;
    }
  }

  // Detach servos on idle to reduce jitter
  if (servosAttached && (millis() - lastCmdMs > SERVO_IDLE_TIMEOUT_MS)) {
    baseServo.detach();
    shoulderServo.detach();
    elbowServo.detach();
    wristServo.detach();
    gripperServo.detach();
    servosAttached = false;
  }

  // Update LED breathing effect
  unsigned long currentMillis = millis();
  if (currentMillis - lastLedUpdate >= LED_UPDATE_INTERVAL) {
    lastLedUpdate = currentMillis;

    ledBrightness += ledDirection;
    if (ledBrightness >= 255) {
      ledBrightness = 255;
      ledDirection = -1;
    } else if (ledBrightness <= 25) {
      ledBrightness = 25;
      ledDirection = 1;
    }

    analogWrite(LED_PIN, ledBrightness);
  }

  // Update MLX sensor reading (non-blocking)
  if (currentMillis - lastMLXUpdate >= MLX_UPDATE_INTERVAL) {
    lastMLXUpdate = currentMillis;
    if (!mlx_inflight) {
      mlx.startMeasurement(mlx_flags);
      if (ambient_mlx_ready) {
        mlx_ambient.startMeasurement(mlx_flags);
      }
      mlx_start_ms = currentMillis;
      mlx_inflight = true;
    }
  }

  // If a measurement completed, only print when there's space to avoid blocking.
  if (mlx_inflight && (currentMillis - mlx_start_ms >= mlx_conv_ms)) {
    mlx.readMeasurement(mlx_flags, raw_data);
    data = mlx.convertRaw(raw_data);
    taredZ = data.z + 18630;

    if (ambient_mlx_ready) {
      mlx_ambient.readMeasurement(mlx_flags, raw_data_ambient);
      data_ambient = mlx_ambient.convertRaw(raw_data_ambient);
      taredZAmbient = data_ambient.z + 18630;
    } else {
      data_ambient.x = 0;
      data_ambient.y = 0;
      taredZAmbient = 0;
    }

    // Print exactly 6 values for hardware interface parser:
    // primary_x,primary_y,primary_z,ambient_x,ambient_y,ambient_z
    // Guard against Serial TX blocking which can introduce jitter.
    // Nano TX buffer is typically 64 bytes; requiring 64 can starve output.
    if (Serial.availableForWrite() >= 48) {
      Serial.print(data.x);
      Serial.print(",");
      Serial.print(data.y);
      Serial.print(",");
      Serial.print(taredZ);
      Serial.print(",");
      Serial.print(data_ambient.x);
      Serial.print(",");
      Serial.print(data_ambient.y);
      Serial.print(",");
      Serial.println(taredZAmbient);
    }

    mlx_inflight = false;
  }
}

void processCommand(String command) {
  if (command.length() < 4) return;

  char joint = command.charAt(0);
  
  // Handle position read request
  if (command == "?") {
    // Send current positions: base,shoulder,elbow,wrist,gripper
    Serial.print(currentBase);
    Serial.print(",");
    Serial.print(currentShoulder);
    Serial.print(",");
    Serial.print(currentElbow);
    Serial.print(",");
    Serial.print(currentWrist);
    Serial.print(",");
    Serial.print(currentGripper);
    Serial.println();
    return;
  }
  
  int angle = command.substring(1).toInt();

  if (angle < 0 || angle > MAX_USER_ANGLE) return;

  // Re-attach on first command after idle and restore current positions
  if (!servosAttached) {
    baseServo.attach(3, MIN_PULSE_WIDTH, MAX_PULSE_WIDTH);
    shoulderServo.attach(5, MIN_PULSE_WIDTH, MAX_PULSE_WIDTH);
    elbowServo.attach(6, MIN_PULSE_WIDTH, MAX_PULSE_WIDTH);
    wristServo.attach(9, MIN_PULSE_WIDTH, MAX_PULSE_WIDTH);
    gripperServo.attach(10, MIN_PULSE_WIDTH, MAX_PULSE_WIDTH);
    servosAttached = true;

    setServoPosition(baseServo, currentBase);
    setServoPosition(shoulderServo, currentShoulder);
    setServoPosition(elbowServo, currentElbow);
    setServoPosition(wristServo, currentWrist);
    setServoPosition(gripperServo, currentGripper);
  }

  lastCmdMs = millis();

  switch (joint) {
    case 'b': 
      setServoPosition(baseServo, angle); 
      currentBase = angle;
      break;
    case 's': 
      setServoPosition(shoulderServo, angle); 
      currentShoulder = angle;
      break;
    case 'e': 
      angle = angle+7.5; // Elbow offset
      if (angle > MAX_USER_ANGLE) angle = MAX_USER_ANGLE;
      setServoPosition(elbowServo, angle);
      currentElbow = angle;
      break;
    case 'w':
      angle = angle+5; // Wrist offset
      if (angle > MAX_USER_ANGLE) angle = MAX_USER_ANGLE;
      setServoPosition(wristServo, angle);
      currentWrist = angle;
      break;
    case 'g': 
      setServoPosition(gripperServo, angle); 
      currentGripper = angle;
      break;
    default: break;
  }
}

void setServoPosition(Servo &servo, int angle) {
  angle = constrain(angle, 0, MAX_USER_ANGLE);
  int pulseWidth = map(angle, 0, SERVO_PHYSICAL_ANGLE, MIN_PULSE_WIDTH, MAX_PULSE_WIDTH);
  servo.writeMicroseconds(pulseWidth);
}

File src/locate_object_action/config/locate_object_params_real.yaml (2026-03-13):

locate_object_action_server:
  ros__parameters:
    # Target position parameters (relative to depth_camera_link_optical frame)
    target_x: 0.0        # Target horizontal position (meters) - centered in camera view
    target_z: 0.375       # Target distance from camera (meters)
    x_tolerance: 0.015    # Horizontal tolerance (meters) - success when |error_x| < x_tolerance
    z_tolerance: 0.02    # Distance tolerance (meters) - success when |error_z| < z_tolerance

    # Control parameters (P control gains)
    k_linear: 2.5       # Lowered for smoother forward/back movement on real robot
    k_angular: 5.0       # Lowered for smoother heading corrections
    max_linear_vel: 0.2   # Reduced cap for less aggressive movement (m/s)
    max_angular_vel: 0.3  # Reduced cap for less aggressive turning (rad/s)
    min_linear_vel: 0.05   # Minimum non-zero linear velocity to overcome stiction
    min_angular_vel: 0.20  # Minimum non-zero angular velocity to overcome stiction
    z_offset_correction: 0.05  # Distance correction added to raw z before control

    # Camera parameters - REAL ROBOT (Arducam ToF)
    # NOTE: These are estimated defaults - tune after testing on real hardware
    h_fov: 1.3           # Horizontal field of view in radians (~74.5 degrees) - typical for Arducam ToF
    aspect_ratio: 1.333  # Aspect ratio (width/height) - 4:3
    camera_frame: 'depth_camera_link_optical'
    image_width: 1280     # Image width in pixels (HQVGA mode)
    image_height: 720    # Image height in pixels (HQVGA mode)
    depth_sample_size: 5 # Number of pixels (NxN window) to average for depth calculation
    bbox_shift_ratio: 0.2 # Horizontal shift for depth sampling as ratio of bbox height (compensates for RGB/depth camera offset)

    # Y-value override (for debugging/testing)
    override_y_value: true   # Enable to force Y value to fixed_y_value (disables calculated Y from depth camera)
    fixed_y_value: 0.07       # Fixed Y value (meters) when override_y_value is true

    # Debug visualization (annotated frames)
    enable_debug_frames: true
    debug_rgb_topic: '/locate_object/debug/rgb'
    debug_depth_topic: '/locate_object/debug/depth'

    # Operation parameters
    max_detection_attempts: 5   # Maximum number of detection attempts before failure
    control_loop_rate: 2.0      # Control loop frequency (Hz) - balance responsiveness vs API costs
    overall_timeout: 60.0       # Overall operation timeout (seconds)
    api_timeout: 10.0           # Gemini API timeout (seconds)
    movement_settle_time: 0.3   # Time to wait after sending velocity command (seconds)

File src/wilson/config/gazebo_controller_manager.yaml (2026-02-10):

# Referenced by wilson.urdf.xacro

controller_manager:
  ros__parameters:
    use_sim_time: True
    update_rate: 100  # Hz

    joint_state_broadcaster:
      type: joint_state_broadcaster/JointStateBroadcaster

    arm_controller:
      type: joint_trajectory_controller/JointTrajectoryController

    gripper_controller:
      type: joint_trajectory_controller/JointTrajectoryController

    diff_drive_controller:
      type: diff_drive_controller/DiffDriveController



arm_controller:
  ros__parameters:
    use_sim_time: True
    joints:
      - joint_1
      - joint_2
      - joint_3
      - joint_4
      - end_effector_roll_joint
      - end_effector_yaw_joint
    interface_name: position
    
    command_interfaces:
      - position

    state_interfaces:
      - position

    open_loop_control: true
    allow_integration_in_goal_trajectories: true


gripper_controller:
  ros__parameters:
    use_sim_time: True
    joints: 
      - gripper_left_finger_joint
      - gripper_right_finger_joint
    interface_name: position
    
    command_interfaces:
      - position

    state_interfaces:
      - position

    open_loop_control: true
    allow_integration_in_goal_trajectories: true

diff_drive_controller:
  ros__parameters:
    use_sim_time: true

    publish_rate: 50.0

    base_frame_id: base_link

    left_wheel_names: ['left_wheel_joint']
    right_wheel_names: ['right_wheel_joint']
    wheel_separation: 0.245
    wheel_radius: 0.018

    use_stamped_vel: false

    # open_loop: false    

    # wheels_per_side: x
    # wheel_separation_multiplier: x
    # left_wheel_radius_multiplier: x
    # right_wheel_radius_multiplier: x

    # odom_frame_id: x
    # pose_covariance_diagonal: x
    # twist_covariance_diagonal: x
    # open_loop: x
    # enable_odom_tf: x

    # cmd_vel_timeout: x
    # publish_limited_velocity: x
    # velocity_rolling_window_size: x
    

    # linear.x.has_velocity_limits: false
    #linear.x.has_acceleration_limits: true
    # linear.x.has_jerk_limits: false
    # linear.x.max_velocity: NAN
    # linear.x.min_velocity: NAN
    #linear.x.max_acceleration: 0.5
    #linear.x.min_acceleration: -0.5
    # linear.x.max_jerk: NAN
    # linear.x.min_jerk: NAN

    # angular.z.has_velocity_limits: false
    # angular.z.has_acceleration_limits: false
    # angular.z.has_jerk_limits: false
    # angular.z.max_velocity: NAN
    # angular.z.min_velocity: NAN
    # angular.z.max_acceleration: NAN
    # angular.z.min_acceleration: NAN
    # angular.z.max_jerk: NAN
    # angular.z.min_jerk: NAN

joint_state_broadcaster:
  ros__parameters:
    use_sim_time: True

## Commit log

2025-09-20 Wilson clean up, created Gemini folder.
    [arduinobot_controllers.yaml, body_link.STL, camera.xacro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]
2025-09-23 Added system instructions to gemini.
    [wilson_system.ros2_control.xacro]
2025-09-27 Docker initial commit.
    [model-1_2.sdf, model-1_3.sdf, model-1_4.sdf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]
2025-09-28 Updated Docker.
    [wilson_system.ros2_control.xacro]
2025-10-04 added arduino firmware
2025-10-04 removed extra arduinobot files, added arm_control.ino
    [arduinobot_controllers.yaml]
2025-10-06 Added old arm package. Need to tweak approach behavior.
    [create_link.xacro, joint_limits.yaml, link_0.stl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]
2025-10-07 Motors not turning at correct speeds.
    [arduinobot_controllers.yaml, config.txt, wilson_system.ros2_control.xacro]
2025-10-08 Encoders and teleop working
2025-10-08 mtc_tutorial adapted to dynamic vector and wilson_sim broken
    [joint_limits.yaml, ros2_controllers.yaml, wilson.ros2_control.xacro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]
2025-10-11 updated devices
    [wilson_system.ros2_control.xacro]
2025-10-11 updated position limits and added maps
    [wilson_core.xacro, wilson_system.ros2_control.xacro]
2025-10-17 wilson arm to target pose working.
    [end_effector.xacro, wilson_system.ros2_control.xacro]
2025-10-19 fixed gazebo asking for roll and yaw states.
    [end_effector_collisions.xacro, gazebo_controller_manager.yaml, ros2_controllers.yaml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]
2025-10-20 target trajectory working in gazebo
    [wilson_core.xacro]
2025-10-21 grab_drink_action created
    [create_link.xacro, joint_limits.yaml, link_0.stl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]
2025-10-25 Locate drink displays image and camera topics fixed
    [camera.xacro, depth_camera.xacro, wilson_core.xacro]
2025-10-25 Correctly moving to drink
    [locate_drink_params_real.yaml, locate_drink_params_sim.yaml]
2025-10-26 added robot cameras only launch
2025-10-26 wilson launch needs fixing
    [robot_controller_manager.yaml]
2025-10-27 drink grab worked!
    [wilson_core_real.xacro, wilson_real.urdf.xacro, wilson_system.ros2_control.xacro]
2025-10-27 nav params reverted to original robot's.
    [turtlebot3_use_sim_time.yaml]
2025-10-27 Grabbing and behaviors tuned. Added move_to_stage action
    [end_effector_collisions.xacro]
2025-10-27 navigation tuned
    [gazebo_controller_manager.yaml, robot_controller_manager.yaml]
2025-12-01 Gemini progress feedback not working
    [raspi_mapper_params_online_async.yaml]
2025-12-06 Fixed some EOL's
    [config.txt]
2025-12-08 switched vscode to wsl wrokspace
    [arduinobot_controllers.yaml, body_link.STL, camera.xacro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]
2026-01-23 Updated real wilson to use rsp using real urdf
2026-02-02 sensor forces being published to /mlx
2026-02-03 Added servo release timeout
2026-02-07 Added mini fridge arduino code and updated ir signaling
2026-02-07 switch ti libgpiod
2026-02-07 switch to rpi-hardware-pwm
2026-02-10 Tuned nav params
    [gazebo_controller_manager.yaml, robot_controller_manager.yaml]
2026-02-13 Drink retrieval updates
    [robot_controller_manager.yaml]
2026-02-13 buttons added with joystick
2026-02-16 updates to locate object params
    [robot_controller_manager.yaml]
2026-02-17 updated sensor params for higher frequency
2026-02-19 Updates to gui and gripper speed
    [joint_limits.yaml]
2026-02-19 ambient sensor complete
    [joint_limits.yaml]
2026-02-22 drink retireval working well.
    [wilson_system.ros2_control.xacro]
